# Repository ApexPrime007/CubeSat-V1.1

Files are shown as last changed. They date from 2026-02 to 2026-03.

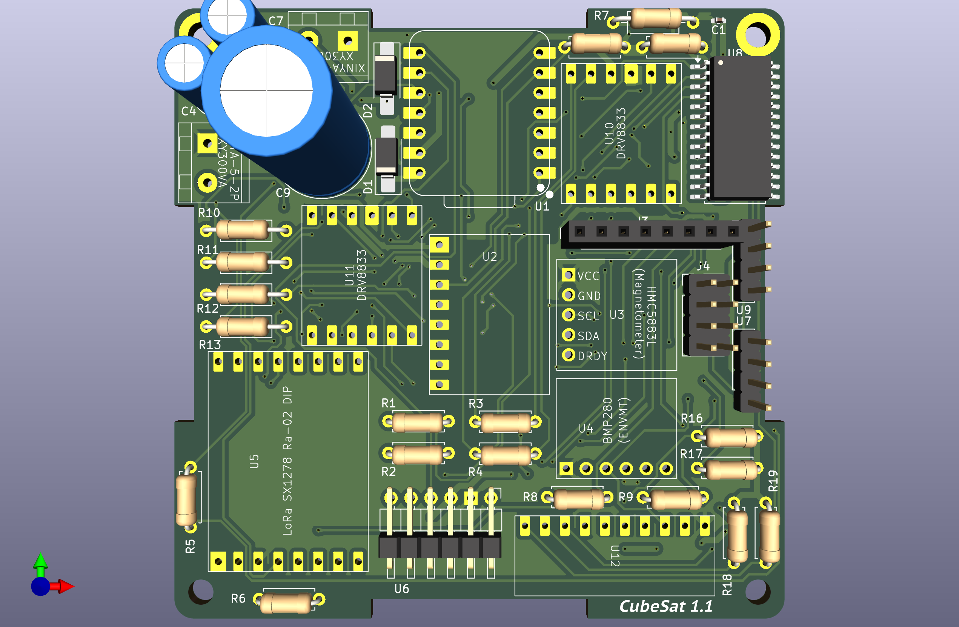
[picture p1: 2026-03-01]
CubeSat V1.1/PCB Design/CubeSat_3D_FrontView.png

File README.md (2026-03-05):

# CubeSat-V1.1
CubeSat prototype of 1U form-factor architecture, integrating inertial navigation, multi-sensor fusion, and quaternion-based EKF attitude estimation using ESP32-S3. Features GNSS time synchronization, solar-powered battery management, onboard imaging, magnetorquer-based ADCS, and long-range LoRa telemetry to a ground control station.

# Overview
The system is structured around three primary subsystems:
1. Navigation & Communication Subsystem (NCS)
2. Electrical Power Subsystem (EPS)
3. Attitude Determination & Control Subsystem (ADCS)

# Key Features
Multi-sensor integration (IMU, magnetometer, barometric sensor, GNSS), 
Quaternion-based attitude estimation with EKF, 
PPS-synchronized GNSS positioning, 
Long-range LoRa telemetry communication, 
Onboard camera image capture and transmission, 
Solar-powered battery charging and power monitoring, 
Magnetorquer-based magnetic attitude control.

# System Architecture
The ESP32-S3 acts as the central processing unit, handling:
I2C/SPI/UART-based sensor communication, 
Real-time data acquisition and calibration, 
Sensor fusion and state estimation, 
Telemetry data packaging and transmission, 
Power-aware embedded operation.

# Power System
The CubeSat prototype includes a solar-powered energy subsystem consisting of:
Solar panels for energy harvesting, 
LiPo battery for energy storage, 
Charging and protection circuitry, 
Embedded power monitoring.

# Attitude Determination & Control
Attitude estimation is performed using quaternion-based filtering techniques (including EKF).
Magnetorquers are implemented for magnetic actuation, providing a lightweight alternative to reaction wheels under CubeSat constraints.

# Applications
Educational CubeSat development, 
Inertial navigation experimentation, 
Embedded systems prototyping, 
Small satellite subsystem research.

# CubeSat Avionics System Architecture
CubeSat_ProcessFlow
This diagram represents the complete avionics data and power architecture of the CubeSat. It shows how power is distributed, how sensors communicate with the flight computer, how attitude is estimated and controlled, and how telemetry and payload data are stored and transmitted to the ground station.

The system is centered around the **ESP32-S3 Sense Flight Computer**, which manages all onboard sensors, performs data fusion, controls the attitude system, and handles telemetry transmission.

# 1. Power System Architecture
The spacecraft power system begins with the **Power System**(Solar Panels), which supplies energy to the onboard **battery**. The battery stores electrical energy generated from solar panels and supplies it to the rest of the spacecraft.The battery output is regulated using **Boost/Buck Converters** to generate stable voltage rails required by different subsystems.

Two voltage rails are generated:
### 5V Rail
The **5V rail** powers components that require higher voltage operation. These include:
* ESP32-S3 Sense Flight Computer
* 5V Current Sensor (for monitoring power consumption)
* Motor drivers used for attitude control

### 3.3V Rail
The **3.3V rail** powers all digital electronics and sensors including:
* IMU sensor
* Magnetometer
* Pressure sensor
* ADC for analog sensors
* LoRa module

Current sensors on both rails continuously monitor power usage and report the values to the flight computer.

# 2. Flight Computer
The **ESP32-S3 Sense** serves as the central processing unit of the CubeSat.
Its responsibilities include:
* Sensor data collection
* Attitude determination
* Attitude control
* Payload management
* Telemetry generation
* Communication with the ground station

The flight computer communicates with different subsystems using three main communication interfaces:
* **UART**
* **I²C Bus**
* **SPI Bus**

# 3. GNSS Navigation System
The CubeSat uses the **AI Thinker GP-02 GNSS Receiver** for positioning and time synchronization.
Communication between the GNSS module and the flight computer occurs through **UART**.

The GNSS receiver provides:
* Position data (latitude, longitude, altitude)
* Precise time synchronization
* Velocity information

This information is used for:
* Orbit determination
* Timestamping telemetry
* Navigation reference

# 4. I²C Sensor Network
Most sensors are connected to the **I²C Bus**, which allows multiple devices to communicate using only two wires.

The following sensors are connected via I²C:
### MPU6050 Accelerometer + Gyroscope
Measures:
* Linear acceleration
* Angular velocity
These measurements provide motion data required for attitude estimation.

### QMC5883L Magnetometer
Measures the **Earth’s magnetic field vector**, which is used for:
* Determining spacecraft heading
* Supporting attitude determination algorithms

### BMP280 Pressure Sensor
Measures atmospheric pressure and temperature.

Although pressure sensing has limited use in orbit, it can assist during **ground testing and launch phase monitoring**.

### MCP23017 GPIO Expander

Provides additional digital input/output pins to the flight computer.
This allows the system to connect extra sensors or control lines, in this case Motor Drivers, because exhaustion of the microcontroller GPIO pins.

### ADS1115 Analog Sensor Interface
The **ADS1115** is a high-resolution analog-to-digital converter.
It reads analog signals from **LDR Sun Sensors**.

# 5. Sun Sensor System
Multiple **LDR-based sun sensors** are mounted on different faces of the CubeSat.
Their readings are processed to determine the **direction of the Sun relative to the spacecraft**.
Processing flow:
```
LDR Sun Sensors
      ↓
ADS1115 ADC
      ↓
Sun Direction Detection
```

The calculated sun vector helps determine spacecraft orientation relative to the Sun.

# 6. 10-DOF IMU Fusion
The CubeSat performs **10 Degree-of-Freedom sensor fusion** using data from:

* MPU6050 (Accelerometer + Gyroscope)
* QMC5883L (Magnetometer)
* BMP280 (Pressure & Temperature)

This fusion algorithm estimates the spacecraft’s **attitude and orientation in space**.

Outputs include:
* Roll
* Pitch
* Yaw
* Orientation quaternion or Euler angles

# 7. Orientation Estimation
The **orientation estimation module** combines:
* IMU data
* Magnetic field data
* Sun direction vector

Using sensor fusion algorithms such as:
* Complementary filter
* Extended Kalman filter
* Madgwick filter

The output is a stable estimate of spacecraft attitude.

# 8. Attitude Control System
The spacecraft controls its orientation using **magnetorquers**.
The control loop operates as follows:
```
Orientation Estimation
        ↓
Magnetorquer Control
        ↓
DRV Motor Drivers
```
The **DRV motor drivers** control the current flowing through magnetorquer coils, generating magnetic dipoles that interact with Earth’s magnetic field to rotate the spacecraft.

# 9. Payload System (Camera)
The CubeSat includes an **OV2640 Camera Module** connected via the **SPI bus**.
The payload operation is scheduled to capture images periodically:
```
OV2640 Camera
      ↓
Capture Image Every 15 Minutes
      ↓
Store to SD Card
```
Images are then stored for later downlink.

# 10. Data Storage
All mission data is stored on the **on-board SD card**.

The SD card stores:
* Sensor data
* GNSS data
* Attitude information
* Captured images
* System logs

This ensures that no critical data is lost even if communication with the ground station is temporarily unavailable.

# 11. Telemetry Generation
Telemetry packets are prepared using the collected data.
The telemetry preparation stage includes:
* Sensor readings
* Attitude estimates
* Power system data
* GNSS position
* System health status
```
Log All Telemetry Data
        ↓
Prepare Telemetry Packet
```

# 12. Communication System
Telemetry is transmitted using the **LoRa SX1278 Radio Module**.
Communication flow:

```
Telemetry Packet
       ↓
LoRa SX1278 Radio
       ↓
Ground Control Station
```
The ground station receives the packets for:
* Mission monitoring
* Data analysis
* Command uplink

# 13. SPI Bus Conflict Control
The **SPI bus** is shared between:
* Camera module
* SD card
* LoRa radio

A **conflict control mechanism** ensures that only one device communicates on the SPI bus at a time, preventing data collisions.

# 14. Complete System Operation
The overall spacecraft operation loop follows this sequence:
1. Power system distributes regulated voltages.
2. Flight computer collects data from all sensors.
3. IMU fusion estimates spacecraft orientation.
4. Sun sensors determine sun direction.
5. Magnetorquer control adjusts spacecraft attitude.
6. Camera captures images periodically.
7. All data is logged to the SD card.
8. Telemetry packets are prepared.
9. LoRa radio transmits data to the ground station.

 This architecture ensures:

* Reliable **attitude determination**
* Efficient **power monitoring**
* Robust **data storage**
* Continuous **telemetry transmission**
* Integrated **Attitude Determination and Control System**

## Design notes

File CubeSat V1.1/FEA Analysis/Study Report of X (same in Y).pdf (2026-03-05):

# Study Report of X (same in Y)

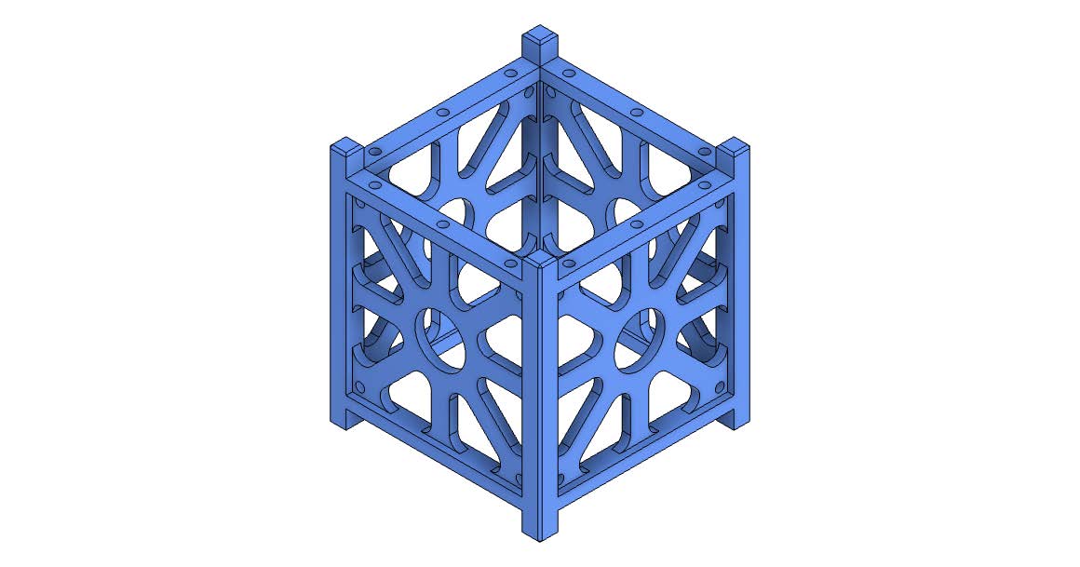
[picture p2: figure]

Analyzed File | CubeSat Structure - Main Body | Version | Autodesk Fusion (2606.1.36)
Creation Date | 2026-02-27, 20:01:35 | Author | Kumar Utkarsh

## Report Properties

Report Properties
Title | Studies
Author | Kumar Utkarsh

## Simulation Model 1

## Study 2 - Static Stress

## Study Properties

Study Properties
Study Type | Static Stress
Last Modification Date | 2026-02-27, 18:32:47

## Study Setup

Settings
General
Contact Tolerance | 0.10 mm
Remove Rigid Body Modes | No
Mesh
Average Element Size (% of model size) - Solids | 10
Scale Mesh Size Per Part | No
Average Element Size (absolute value) | -
Element Order | Parabolic
Create Curved Mesh Elements | Yes
Max. Turn Angle on Curves (Deg.) | 60
Max. Adjacent Mesh Size Ratio | 1.5
Max. Aspect Ratio | 10
Minimum Element Size (% of average size) | 20
Adaptive Mesh Refinement
Number of Refinement Steps | 0
Results Convergence Tolerance (%) | 20
Portion of Elements to Refine (%) | 10
Results for Baseline Accuracy | von Mises Stress

Materials
PLA
Components
Component | Strength
Body1 | Yield Strength
Properties
Density | 1.240E-06 kg / mm^3
Young's Modulus | 2800.00 MPa
Poisson's Ratio | 0.36
Yield Strength | 39.995 MPa
Ultimate Tensile Strength | 49.599 MPa
Thermal Conductivity | 1.600E-04 W / (mm K)
Thermal Expansion Coefficient | 7.020E-05 / K
Specific Heat | 1795.00 J / (kg K)

Contacts
Contact Type | Contact Set | Penetration Type | Bodies | Entities
Bonded
[M] Bonded1 | Symmetric | [Body1 Simulation Model 1:1||Body1 Simulation Model 1:1] | [Face 1415||Face 1441]
[M] Bonded2 | Symmetric | [Body1 Simulation Model 1:1||Body1 Simulation Model 1:1] | [Face 1461||Face 1460]

Mesh
Type | Solids
Nodes | 39529
Elements | 20437

## Load Case1

Constraints
Fixed1

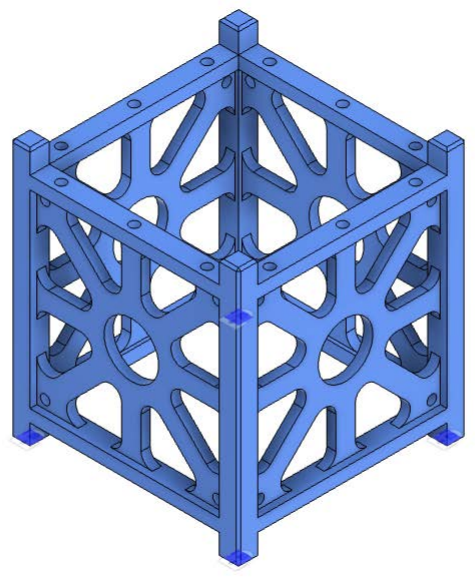
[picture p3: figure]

Type | Fixed
Ux | Fixed
Uy | Fixed
Uz | Fixed

Loads
Linear Global Load1
Type | Linear Global Load
Acceleration
X Value | 9.80 m / s^2
Y Value | 0.00 m / s^2
Z Value | 0.00 m / s^2

## Load Case1 - Guided Results

Safety Factor

With the analysis criteria in this study setup, the design is expected to bend permanently or break.

Next Steps

Below Safety Factor Target Validate your study setup
Check the loads are not set too high
Check the mesh refinement and consider increasing it in areas of high stress
Confirm your Safety Factor requirement
If the Displacement result shows high displacement, consider running a Nonlinear study to gain more insight Check other results
Examine the Below target Result visualization to see where the weakest areas are
Check the stress result to see if, and where, the material might yield
Check the displacement result to see how far from its original alignment the model has moved
Look at other results, such as reaction forces to check your study set up, or strain to check your material performance Strengthen weak areas
Add more material to weak areas
Select a material with a higher yield strength
Stiffen the design
Modify the shape with a Generative Design study Generate alternative designs Add more material to weak areas
Select a material with a higher yield strength Stiffen the design
Modify the shape with a Generative Design study Above Safety Factor Limit
Validate your study setup
Check the loads are not set too high
Check the mesh refinement and consider increasing it in areas of high stress
Confirm your Safety Factor requirement
If the Displacement result shows high displacement, consider running a Nonlinear study to gain more insight Check other results
Examine the Below target Result visualization to see where the weakest areas are
Check the stress result to see if, and where, the material might yield
Check the displacement result to see how far from its original alignment the model has moved
Look at other results, such as reaction forces to check your study set up, or strain to check your material performance Lightweight the design
Set a Safety Factor upper limit to find where material can be removed
Remove material from areas that exceed the Safety Factor upper limit
Generate alternative designs In the Generative Design workspace, create design modifications Remove unnecessary material using a Shape Optimization study

## Load Case1 - Results

Result Summary
Result type | Sub-result | Minimum | Maximum
Safety Factor
| Safety Factor | 1,119.086 | 1.66E+06
Stress
Von Mises | 2.409E-05 MPa | 0.036 MPa
1st Principal | −0.027 MPa | 0.064 MPa
3rd Principal | −0.064 MPa | 0.026 MPa
Normal XX | −0.028 MPa | 0.028 MPa
Normal YY | −0.03 MPa | 0.03 MPa
Normal ZZ | −0.062 MPa | 0.062 MPa
Shear XY | −0.003 MPa | 0.003 MPa
Shear YZ | −0.007 MPa | 0.007 MPa
Shear XZ | −0.009 MPa | 0.011 MPa
Displacement
Total | 0 mm | 8.799E-04 mm
X | 0 mm | 8.794E-04 mm
Y | −6.351E-05 mm | 6.424E-05 mm
Z | −7.924E-05 mm | 7.802E-05 mm
Reaction Force
Total | 0 N | 0.168 N
X | −0.052 N | 0.005 N
Y | −0.02 N | 0.025 N
Z | −0.159 N | 0.158 N
Strain
Equivalent | 1.291E-08 | 1.524E-05
1st Principal | 6.081E-09 | 1.73E-05
3rd Principal | −1.74E-05 | −6.129E-09
Normal XX | −5.858E-06 | 5.792E-06
Normal YY | −2.883E-06 | 2.801E-06
Normal ZZ | −1.478E-05 | 1.48E-05
Shear XY | −3.16E-06 | 3.042E-06
Shear YZ | −6.371E-06 | 6.545E-06
Shear XZ | −8.927E-06 | 1.122E-05
Contact Pressure
Total | 0 MPa | 0.058 MPa
X | −0.011 MPa | 0.01 MPa
Y | −0.01 MPa | 0.009 MPa
Z | −0.057 MPa | 0.057 MPa
Contact Force
Total | 0 N | 0.017 N
X | −0.012 N | 0.009 N
Y | −0.017 N | 0.016 N
Z | −0.009 N | 0.009 N

Safety Factor
Safety Factor

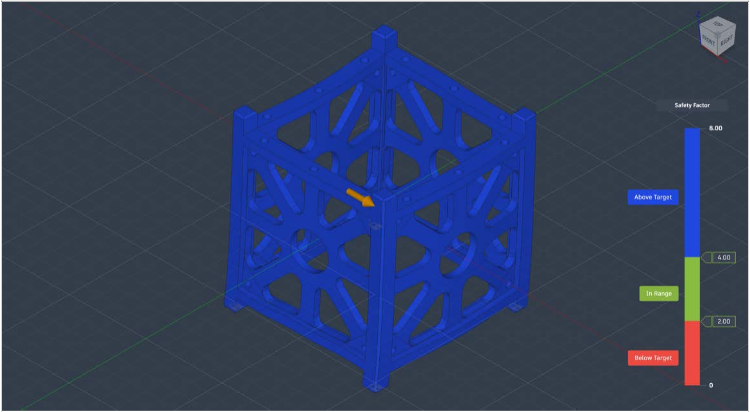
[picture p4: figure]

Stress
Von Mises

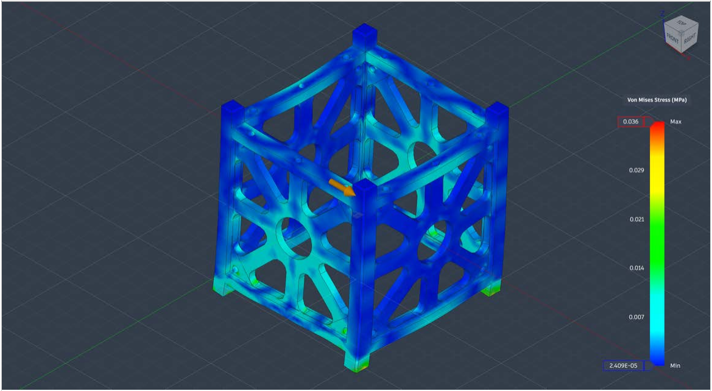
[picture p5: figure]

1st Principal

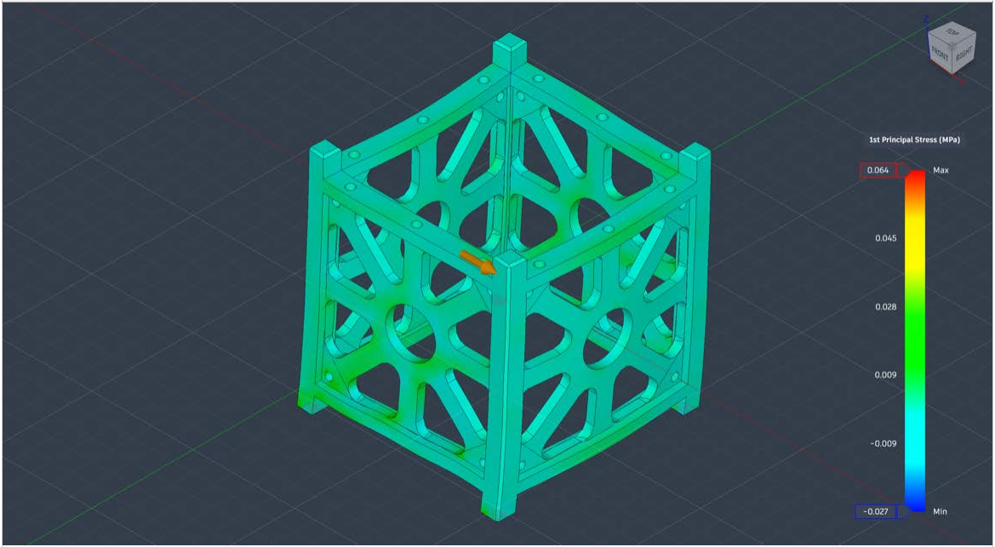
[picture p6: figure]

3rd Principal

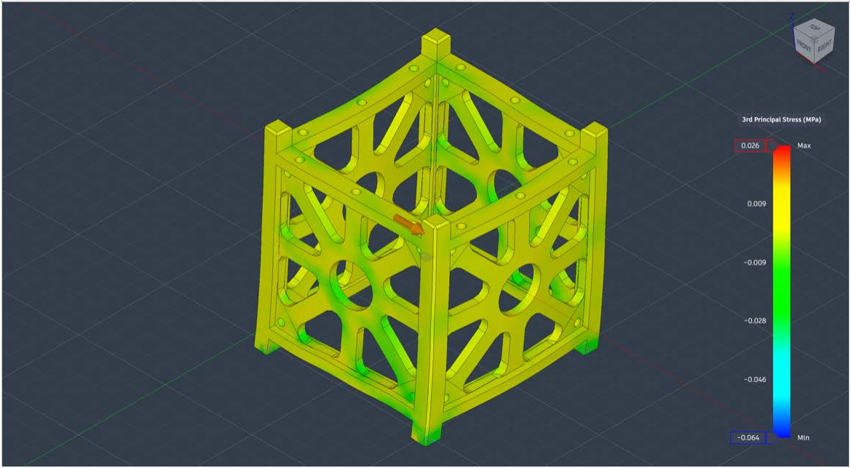
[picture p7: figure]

Displacement
Total

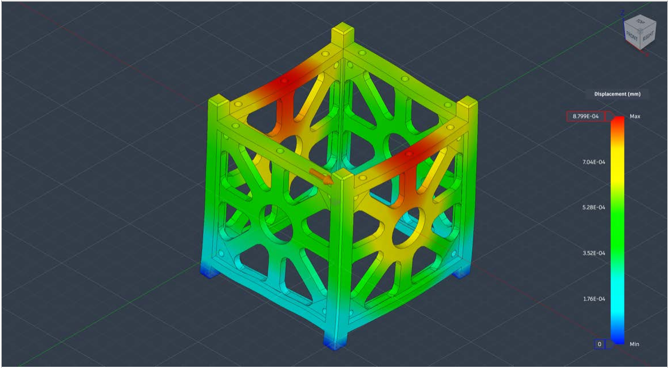
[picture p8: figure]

## Load Case2

Constraints
Fixed3

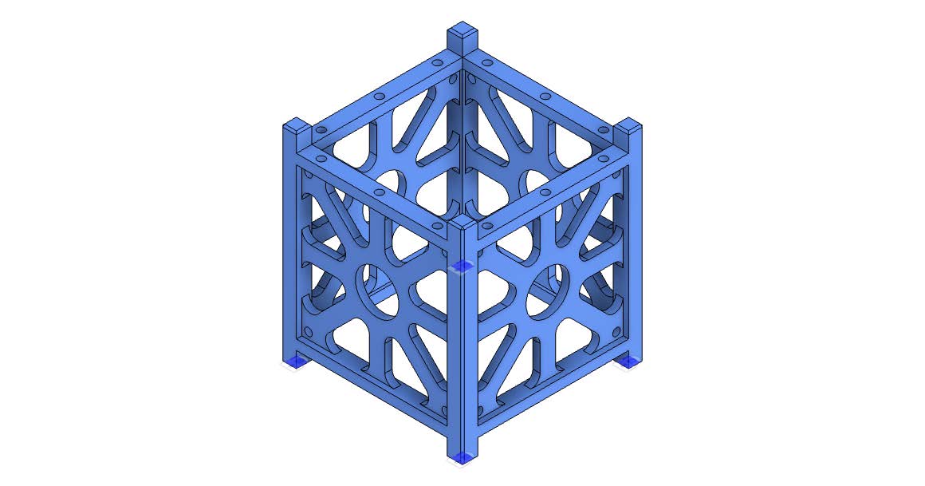
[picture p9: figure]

Type | Fixed
Ux | Fixed
Uy | Fixed
Uz | Fixed

Loads
Linear Global Load2
Type | Linear Global Load
Acceleration
X Value | 19.60 m / s^2
Y Value | 0.00 m / s^2
Z Value | 0.00 m / s^2

## Load Case2 - Guided Results

Safety Factor

With the analysis criteria in this study setup, the design is expected to bend permanently or break.

Next Steps

Below Safety Factor Target Validate your study setup
Check the loads are not set too high
Check the mesh refinement and consider increasing it in areas of high stress
Confirm your Safety Factor requirement
If the Displacement result shows high displacement, consider running a Nonlinear study to gain more insight Check other results
Examine the Below target Result visualization to see where the weakest areas are
Check the stress result to see if, and where, the material might yield
Check the displacement result to see how far from its original alignment the model has moved
Look at other results, such as reaction forces to check your study set up, or strain to check your material performance Strengthen weak areas
Add more material to weak areas
Select a material with a higher yield strength
Stiffen the design
Modify the shape with a Generative Design study Generate alternative designs Add more material to weak areas
Select a material with a higher yield strength Stiffen the design
Modify the shape with a Generative Design study Above Safety Factor Limit
Validate your study setup
Check the loads are not set too high
Check the mesh refinement and consider increasing it in areas of high stress
Confirm your Safety Factor requirement
If the Displacement result shows high displacement, consider running a Nonlinear study to gain more insight Check other results
Examine the Below target Result visualization to see where the weakest areas are
Check the stress result to see if, and where, the material might yield
Check the displacement result to see how far from its original alignment the model has moved
Look at other results, such as reaction forces to check your study set up, or strain to check your material performance Lightweight the design
Set a Safety Factor upper limit to find where material can be removed
Remove material from areas that exceed the Safety Factor upper limit
Generate alternative designs In the Generative Design workspace, create design modifications Remove unnecessary material using a Shape Optimization study

## Load Case2 - Results

Result Summary
Result type | Sub-result | Minimum | Maximum
Safety Factor
| Safety Factor | 559.543 | 830,076.00
Stress
Von Mises | 4.818E-05 MPa | 0.071 MPa
1st Principal | −0.053 MPa | 0.127 MPa
3rd Principal | −0.127 MPa | 0.053 MPa
Normal XX | −0.056 MPa | 0.055 MPa
Normal YY | −0.059 MPa | 0.059 MPa

Header
Report Properties
Simulation Model 1
Study 2 - Static Stress
Study Properties
Study Setup
Settings
Materials
Contacts
Mesh
Load Case1
Constraints
Loads
Guided Results
SafetyFactor
Results
Result Summary

Stress
Displacement
Load Case2

Guided Results
SafetyFactor
Results
Result Summary

Stress

Load Case3

Guided Results
SafetyFactor
Results
Result Summary

Stress

Load Case4

Guided Results
SafetyFactor
Results
Result Summary

Stress

Load Case5

Guided Results
SafetyFactor
Results
Result Summary

Stress
Displacement
Load Case6
Constraints
Loads
Guided Results
SafetyFactor
Results
Result Summary
Safety Factor
Stress
Displacement
Load Case7
Constraints
Loads
Guided Results
SafetyFactor
Results
Result Summary
Safety Factor
Stress
Displacement
Load Case8
Constraints
Loads
Guided Results
SafetyFactor
Results
Result Summary
Safety Factor
Stress
Displacement

Normal ZZ | −0.124 MPa | 0.124 MPa
Shear XY | −0.006 MPa | 0.006 MPa
Shear YZ | −0.013 MPa | 0.013 MPa
Shear XZ | −0.018 MPa | 0.023 MPa
Total | 0 mm | 0.002 mm
X | 0 mm | 0.002 mm
Y | −1.27E-04 mm | 1.285E-04 mm
Z | −1.585E-04 mm | 1.56E-04 mm
Reaction Force
Total | 0 N | 0.336 N
X | −0.103 N | 0.01 N
Y | −0.04 N | 0.05 N
Z | −0.317 N | 0.316 N
Strain
Equivalent | 2.583E-08 | 3.047E-05
1st Principal | 1.216E-08 | 3.461E-05
3rd Principal | −3.48E-05 | −1.226E-08
Normal XX | −1.172E-05 | 1.158E-05
Normal YY | −5.766E-06 | 5.602E-06
Normal ZZ | −2.955E-05 | 2.959E-05
Shear XY | −6.32E-06 | 6.085E-06
Shear YZ | −1.274E-05 | 1.309E-05
Shear XZ | −1.785E-05 | 2.244E-05
Contact Pressure
Total | 0 MPa | 0.117 MPa
X | −0.023 MPa | 0.021 MPa
Y | −0.019 MPa | 0.019 MPa
Z | −0.115 MPa | 0.114 MPa
Contact Force
Total | 0 N | 0.034 N
X | −0.024 N | 0.018 N
Y | −0.034 N | 0.033 N
Z | −0.018 N | 0.018 N

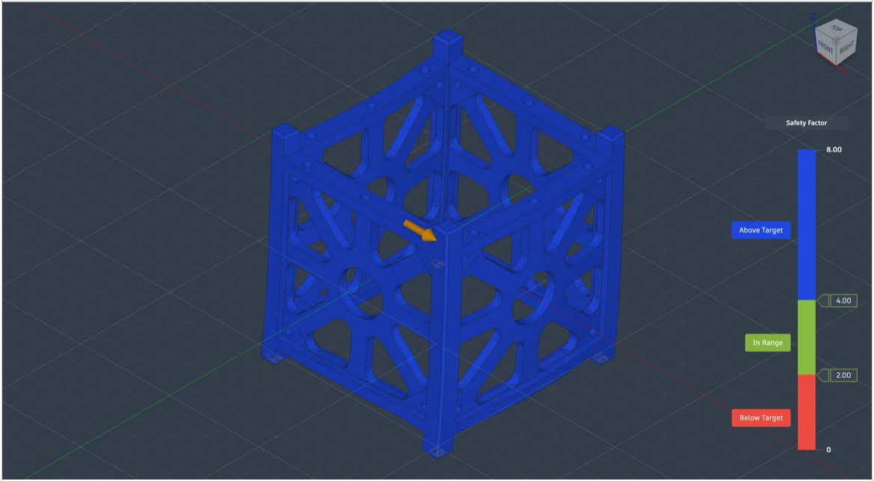
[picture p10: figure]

Stress
Von Mises

1st Principal

3rd Principal

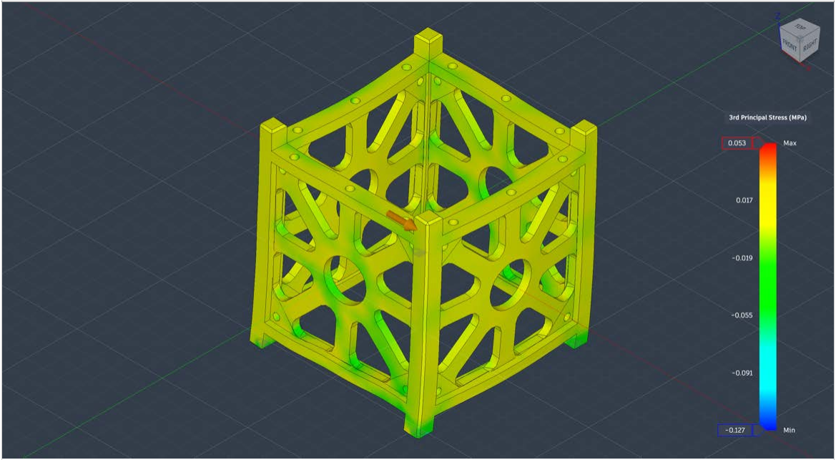
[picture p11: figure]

Displacement
Total

## Load Case3

Constraints
Fixed4
Type | Fixed
Ux | Fixed
Uy | Fixed
Uz | Fixed

Loads
Linear Global Load3
Type | Linear Global Load
Acceleration
X Value | 29.40 m / s^2
Y Value | 0.00 m / s^2
Z Value | 0.00 m / s^2

## Load Case3 - Guided Results

Safety Factor

With the analysis criteria in this study setup, the design is expected to bend permanently or break.

Next Steps

Below Safety Factor Target Validate your study setup
Check the loads are not set too high
Check the mesh refinement and consider increasing it in areas of high stress
Confirm your Safety Factor requirement
If the Displacement result shows high displacement, consider running a Nonlinear study to gain more insight Check other results
Examine the Below target Result visualization to see where the weakest areas are
Check the stress result to see if, and where, the material might yield
Check the displacement result to see how far from its original alignment the model has moved
Look at other results, such as reaction forces to check your study set up, or strain to check your material performance Strengthen weak areas
Add more material to weak areas
Select a material with a higher yield strength
Stiffen the design
Modify the shape with a Generative Design study Generate alternative designs Add more material to weak areas
Select a material with a higher yield strength Stiffen the design
Modify the shape with a Generative Design study Above Safety Factor Limit
Validate your study setup
Check the loads are not set too high
Check the mesh refinement and consider increasing it in areas of high stress
Confirm your Safety Factor requirement
If the Displacement result shows high displacement, consider running a Nonlinear study to gain more insight Check other results
Examine the Below target Result visualization to see where the weakest areas are
Check the stress result to see if, and where, the material might yield
Check the displacement result to see how far from its original alignment the model has moved
Look at other results, such as reaction forces to check your study set up, or strain to check your material performance Lightweight the design
Set a Safety Factor upper limit to find where material can be removed
Remove material from areas that exceed the Safety Factor upper limit
Generate alternative designs In the Generative Design workspace, create design modifications Remove unnecessary material using a Shape Optimization study

## Load Case3 - Results

Result Summary
Result type | Sub-result | Minimum | Maximum
Safety Factor
| Safety Factor | 373.029 | 553,384.063
Stress
Von Mises | 7.227E-05 MPa | 0.107 MPa
1st Principal | −0.08 MPa | 0.19 MPa
3rd Principal | −0.191 MPa | 0.079 MPa
Normal XX | −0.083 MPa | 0.083 MPa
Normal YY | −0.089 MPa | 0.089 MPa
Normal ZZ | −0.186 MPa | 0.186 MPa
Shear XY | −0.01 MPa | 0.009 MPa
Shear YZ | −0.02 MPa | 0.02 MPa
Shear XZ | −0.028 MPa | 0.035 MPa
Displacement
Total | 0 mm | 0.003 mm
X | 0 mm | 0.003 mm
Y | −1.905E-04 mm | 1.927E-04 mm
Z | −2.377E-04 mm | 2.341E-04 mm
Reaction Force
Total | 0 N | 0.503 N
X | −0.155 N | 0.015 N
Y | −0.059 N | 0.075 N
Z | −0.476 N | 0.474 N
Strain
Equivalent | 3.874E-08 | 4.571E-05
1st Principal | 1.824E-08 | 5.191E-05
3rd Principal | −5.221E-05 | −1.839E-08
Normal XX | −1.758E-05 | 1.738E-05
Normal YY | −8.649E-06 | 8.402E-06
Normal ZZ | −4.433E-05 | 4.439E-05
Shear XY | −9.481E-06 | 9.127E-06
Shear YZ | −1.911E-05 | 1.964E-05
Shear XZ | −2.678E-05 | 3.366E-05
Contact Pressure
Total | 0 MPa | 0.175 MPa
X | −0.034 MPa | 0.031 MPa
Y | −0.029 MPa | 0.029 MPa
Z | −0.172 MPa | 0.172 MPa
Contact Force
Total | 0 N | 0.051 N
X | −0.036 N | 0.027 N
Y | −0.051 N | 0.049 N
Z | −0.026 N | 0.026 N

Safety Factor
Safety Factor

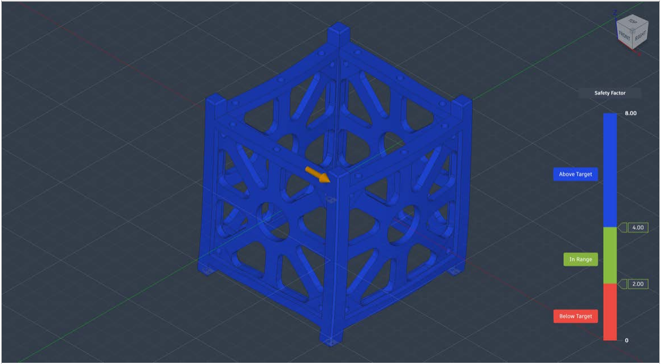
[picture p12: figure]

Stress
Von Mises

1st Principal

3rd Principal

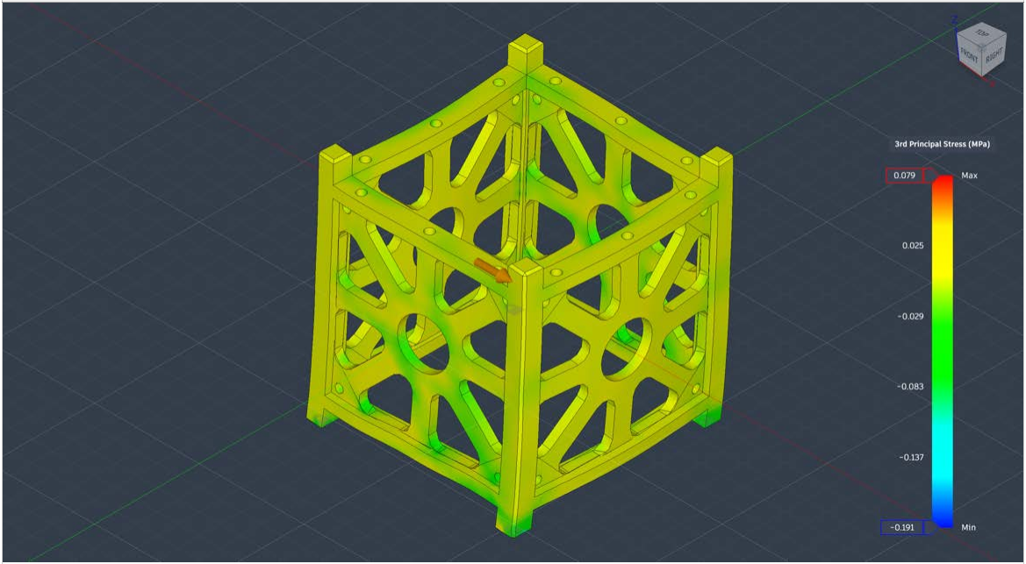
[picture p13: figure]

Displacement
Total

## Load Case4

Constraints
Fixed5
Type | Fixed
Ux | Fixed
Uy | Fixed
Uz | Fixed

Linear Global Load4

Type | Linear Global Load
Acceleration
X Value | 49.00 m / s^2
Y Value | 0.00 m / s^2
Z Value | 0.00 m / s^2

## Load Case4 - Guided Results

With the analysis criteria in this study setup, there is opportunity to reduce the volume of material and cost of this design.

Next Steps

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

## Load Case4 - Results

Result Summary
Result type | Sub-result | Minimum | Maximum
Safety Factor
| Safety Factor | 223.817 | 332,030.406
Stress
Von Mises | 1.205E-04 MPa | 0.179 MPa
1st Principal | −0.133 MPa | 0.317 MPa
3rd Principal | −0.318 MPa | 0.132 MPa
Normal XX | −0.139 MPa | 0.138 MPa
Normal YY | −0.148 MPa | 0.148 MPa
Normal ZZ | −0.31 MPa | 0.31 MPa
Shear XY | −0.016 MPa | 0.016 MPa
Shear YZ | −0.033 MPa | 0.034 MPa
Shear XZ | −0.046 MPa | 0.058 MPa
Displacement
Total | 0 mm | 0.004 mm
X | 0 mm | 0.004 mm
Y | −3.176E-04 mm | 3.212E-04 mm
Z | −3.962E-04 mm | 3.901E-04 mm
Reaction Force
Total | 0 N | 0.839 N
X | −0.258 N | 0.024 N
Y | −0.099 N | 0.124 N
Z | −0.793 N | 0.79 N
Strain
Equivalent | 6.457E-08 | 7.618E-05
1st Principal | 3.04E-08 | 8.652E-05
3rd Principal | −8.701E-05 | −3.065E-08
Normal XX | −2.929E-05 | 2.896E-05
Normal YY | −1.442E-05 | 1.40E-05
Normal ZZ | −7.389E-05 | 7.398E-05
Shear XY | −1.58E-05 | 1.521E-05
Shear YZ | −3.186E-05 | 3.273E-05
Shear XZ | −4.463E-05 | 5.61E-05
Contact Pressure
Total | 0 MPa | 0.292 MPa
X | −0.057 MPa | 0.052 MPa
Y | −0.048 MPa | 0.048 MPa
Z | −0.287 MPa | 0.286 MPa
Contact Force
Total | 0 N | 0.086 N
X | −0.059 N | 0.045 N
Y | −0.085 N | 0.082 N
Z | −0.044 N | 0.044 N

Safety Factor
Safety Factor

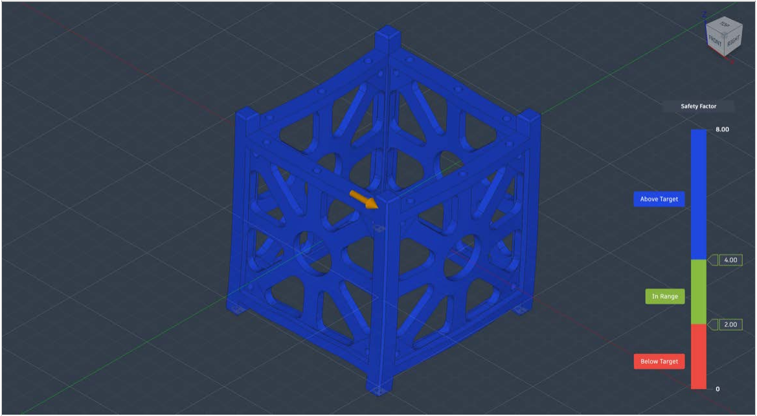
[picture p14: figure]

Stress
Von Mises

1st Principal

3rd Principal

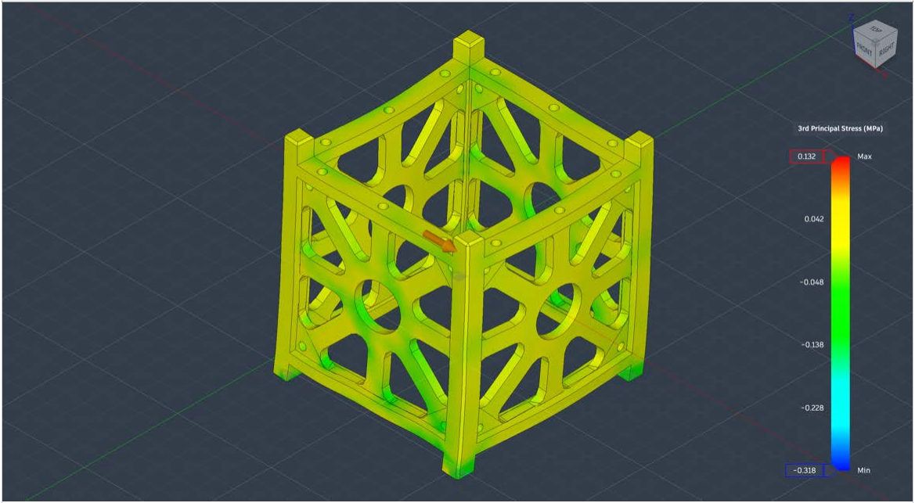
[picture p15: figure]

Displacement
Total

## Load Case5

Constraints
Fixed6
Type | Fixed
Ux | Fixed
Uy | Fixed
Uz | Fixed

Loads
Linear Global Load5
Type | Linear Global Load
Acceleration
X Value | 58.80 m / s^2
Y Value | 0.00 m / s^2
Z Value | 0.00 m / s^2

## Load Case5 - Guided Results

Safety Factor

With the analysis criteria in this study setup, there is opportunity to reduce the volume of material and cost of this design.

Next Steps

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

## Load Case5 - Results

Result Summary
Result type | Sub-result | Minimum | Maximum
Safety Factor
| Safety Factor | 186.514 | 276,692.031
Stress
Von Mises | 1.445E-04 MPa | 0.214 MPa
1st Principal | −0.159 MPa | 0.381 MPa
3rd Principal | −0.381 MPa | 0.159 MPa
Normal XX | −0.166 MPa | 0.166 MPa
Normal YY | −0.178 MPa | 0.177 MPa
Normal ZZ | −0.372 MPa | 0.372 MPa
Shear XY | −0.019 MPa | 0.019 MPa
Shear YZ | −0.039 MPa | 0.04 MPa
Shear XZ | −0.055 MPa | 0.069 MPa
Displacement
Total | 0 mm | 0.005 mm
X | 0 mm | 0.005 mm
Y | −3.811E-04 mm | 3.855E-04 mm
Z | −4.755E-04 mm | 4.681E-04 mm
Reaction Force
Total | 0 N | 1.007 N
X | −0.31 N | 0.029 N
Y | −0.119 N | 0.149 N
Z | −0.952 N | 0.949 N
Strain
Equivalent | 7.749E-08 | 9.141E-05
1st Principal | 3.648E-08 | 1.038E-04
3rd Principal | −1.044E-04 | −3.678E-08
Normal XX | −3.515E-05 | 3.475E-05
Normal YY | −1.73E-05 | 1.68E-05
Normal ZZ | −8.866E-05 | 8.878E-05
Shear XY | −1.896E-05 | 1.825E-05
Shear YZ | −3.823E-05 | 3.927E-05
Shear XZ | −5.356E-05 | 6.732E-05
Contact Pressure
Total | 0 MPa | 0.35 MPa
X | −0.068 MPa | 0.062 MPa
Y | −0.057 MPa | 0.057 MPa
Z | −0.344 MPa | 0.343 MPa
Contact Force
Total | 0 N | 0.103 N
X | −0.071 N | 0.054 N
Y | −0.102 N | 0.098 N
Z | −0.053 N | 0.053 N

Safety Factor
Safety Factor

Stress
Von Mises

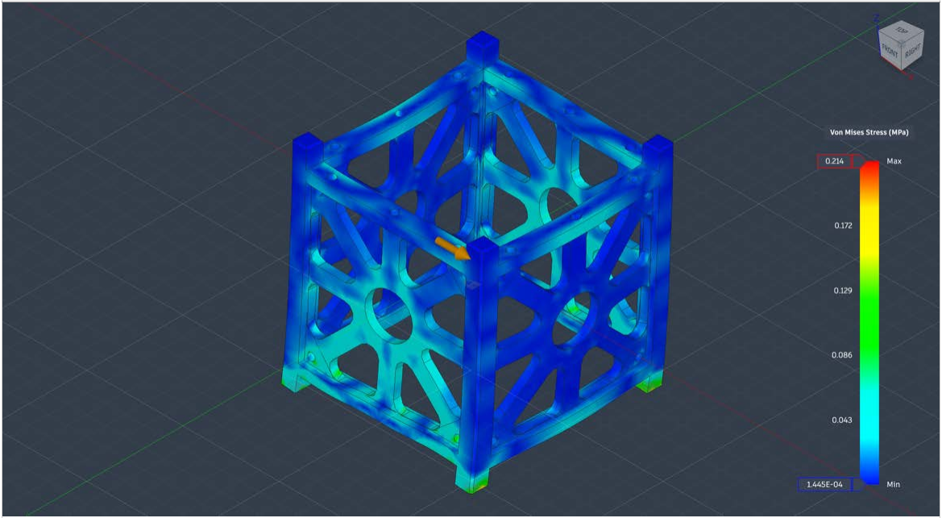
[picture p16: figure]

1st Principal

3rd Principal

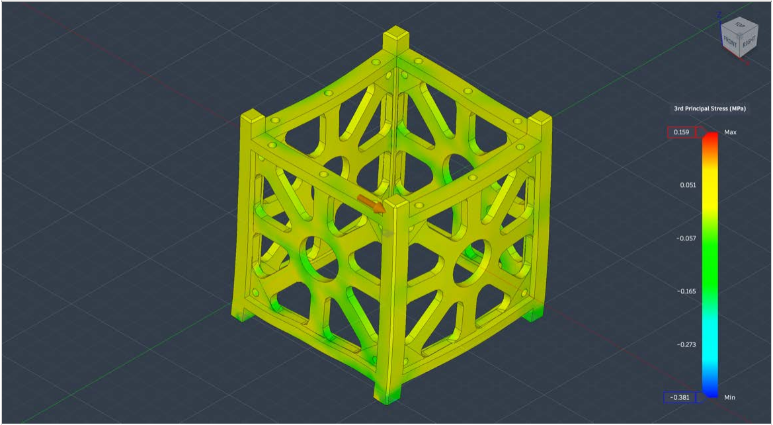
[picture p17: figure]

Total

## Load Case6

Fixed8

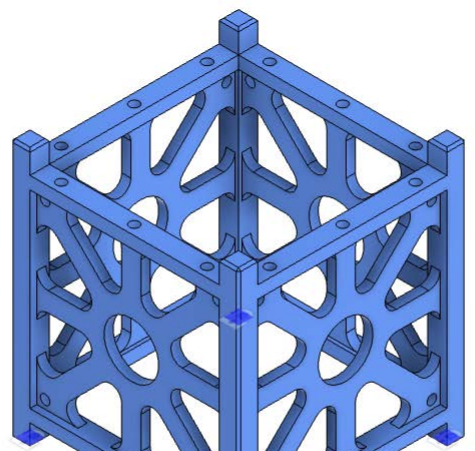
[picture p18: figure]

Type | Fixed
Ux | Fixed
Uy | Fixed
Uz | Fixed

Linear Global Load7

Type | Linear Global Load
Acceleration
X Value | 78.40 m / s^2
Y Value | 0.00 m / s^2
Z Value | 0.00 m / s^2

## Load Case6 - Guided Results

With the analysis criteria in this study setup, there is opportunity to reduce the volume of material and cost of this design.

Next Steps

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

## Load Case6 - Results

Result Summary
Result type | Sub-result | Minimum | Maximum
Safety Factor
| Safety Factor | 139.886 | 207,519.00
Stress
Von Mises | 1.927E-04 MPa | 0.286 MPa
1st Principal | −0.212 MPa | 0.508 MPa
3rd Principal | −0.508 MPa | 0.212 MPa
Normal XX | −0.222 MPa | 0.221 MPa
Normal YY | −0.238 MPa | 0.237 MPa
Normal ZZ | −0.496 MPa | 0.496 MPa
Shear XY | −0.026 MPa | 0.025 MPa
Shear YZ | −0.052 MPa | 0.054 MPa
Shear XZ | −0.073 MPa | 0.092 MPa
Displacement
Total | 0 mm | 0.007 mm
X | 0 mm | 0.007 mm
Y | −5.081E-04 mm | 5.14E-04 mm
Z | −6.339E-04 mm | 6.241E-04 mm
Reaction Force
Total | 0 N | 1.343 N
X | −0.413 N | 0.039 N
Y | −0.159 N | 0.199 N
Z | −1.27 N | 1.265 N
Strain
Equivalent | 1.033E-07 | 1.219E-04
1st Principal | 4.864E-08 | 1.384E-04
3rd Principal | −1.392E-04 | −4.903E-08
Normal XX | −4.687E-05 | 4.634E-05
Normal YY | −2.306E-05 | 2.241E-05
Normal ZZ | −1.182E-04 | 1.184E-04
Shear XY | −2.528E-05 | 2.434E-05
Shear YZ | −5.097E-05 | 5.236E-05
Shear XZ | −7.142E-05 | 8.976E-05
Contact Pressure
Total | 0 MPa | 0.467 MPa
X | −0.091 MPa | 0.083 MPa
Y | −0.076 MPa | 0.076 MPa
Z | −0.459 MPa | 0.457 MPa
Contact Force
Total | 0 N | 0.137 N
X | −0.095 N | 0.072 N
Y | −0.136 N | 0.131 N
Z | −0.071 N | 0.071 N

Safety Factor
Safety Factor

Stress
Von Mises

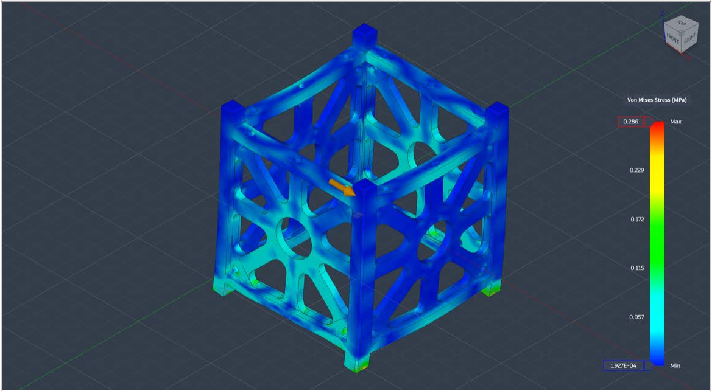
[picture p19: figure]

1st Principal

3rd Principal

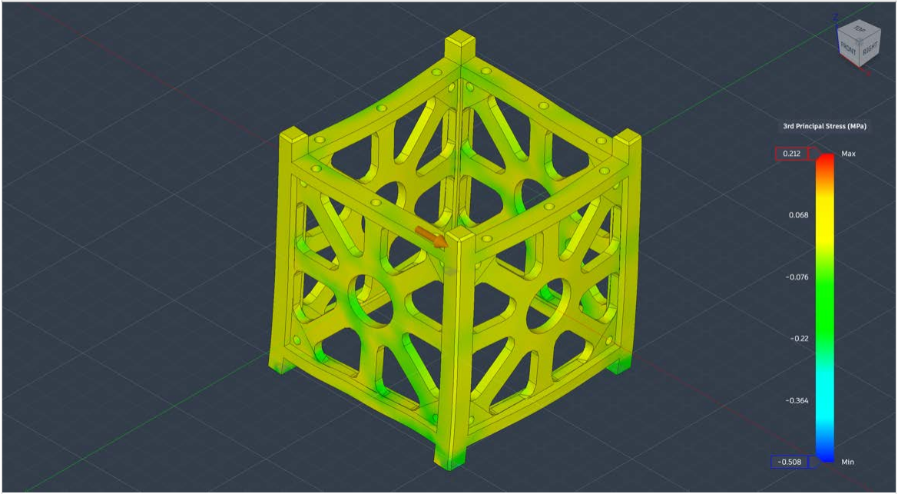
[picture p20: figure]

Displacement
Total

## Load Case7

Constraints
Fixed9
Type | Fixed
Ux | Fixed
Uy | Fixed
Uz | Fixed

Loads
Linear Global Load8
Type | Linear Global Load
Acceleration
X Value | 98.00 m / s^2
Y Value | 0.00 m / s^2
Z Value | 0.00 m / s^2

## Load Case7 - Guided Results

Safety Factor

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

Next Steps

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

## Load Case7 - Results

Result Summary
Result type | Sub-result | Minimum | Maximum
Safety Factor
| Safety Factor | 111.909 | 166,015.203
Stress
Von Mises | 2.409E-04 MPa | 0.357 MPa
1st Principal | −0.266 MPa | 0.635 MPa
3rd Principal | −0.636 MPa | 0.265 MPa
Normal XX | −0.277 MPa | 0.276 MPa
Normal YY | −0.297 MPa | 0.296 MPa
Normal ZZ | −0.62 MPa | 0.62 MPa
Shear XY | −0.033 MPa | 0.031 MPa
Shear YZ | −0.066 MPa | 0.067 MPa
Shear XZ | −0.092 MPa | 0.116 MPa
Displacement
Total | 0 mm | 0.009 mm
X | 0 mm | 0.009 mm
Y | −6.351E-04 mm | 6.424E-04 mm
Z | −7.924E-04 mm | 7.802E-04 mm
Reaction Force
Total | 0 N | 1.678 N
X | −0.516 N | 0.049 N
Y | −0.198 N | 0.249 N
Z | −1.587 N | 1.581 N
Strain
Equivalent | 1.291E-07 | 1.524E-04
1st Principal | 6.081E-08 | 1.73E-04
3rd Principal | −1.74E-04 | −6.129E-08
Normal XX | −5.858E-05 | 5.792E-05
Normal YY | −2.883E-05 | 2.801E-05
Normal ZZ | −1.478E-04 | 1.48E-04
Shear XY | −3.16E-05 | 3.042E-05
Shear YZ | −6.371E-05 | 6.545E-05
Shear XZ | −8.927E-05 | 1.122E-04
Contact Pressure
Total | 0 MPa | 0.584 MPa
X | −0.114 MPa | 0.103 MPa
Y | −0.096 MPa | 0.095 MPa
Z | −0.573 MPa | 0.572 MPa
Contact Force
Total | 0 N | 0.171 N
X | −0.119 N | 0.091 N
Y | −0.169 N | 0.164 N
Z | −0.088 N | 0.088 N

Safety Factor
Safety Factor

Stress
Von Mises

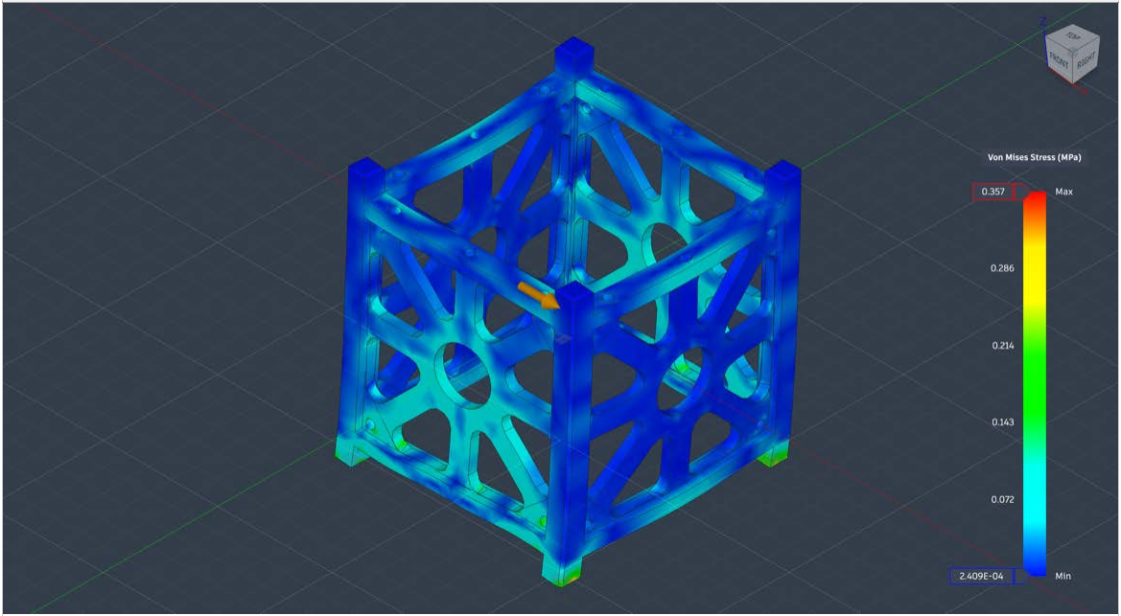
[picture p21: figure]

1st Principal

3rd Principal

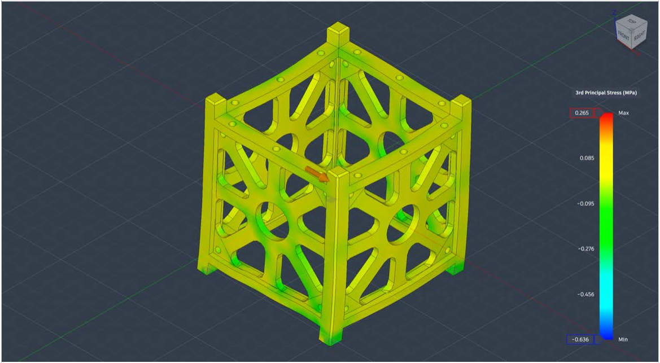
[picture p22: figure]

## Load Case8

Fixed10

Type | Fixed
Ux | Fixed
Uy | Fixed
Uz | Fixed

Loads
Linear Global Load9

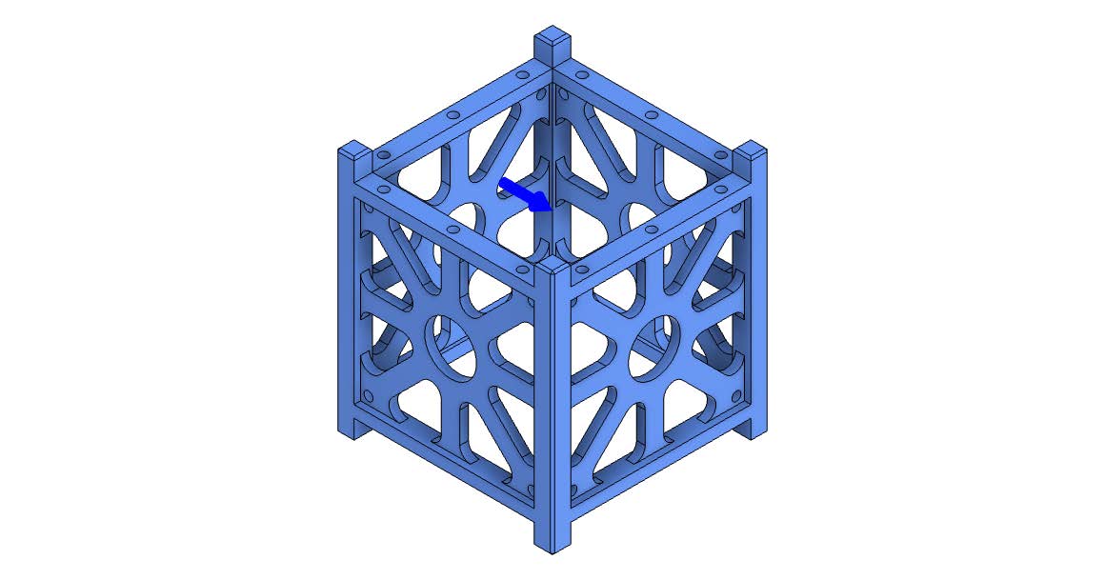
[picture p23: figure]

Type | Linear Global Load
Acceleration
X Value | 147.00 m / s^2
Y Value | 0.00 m / s^2
Z Value | 0.00 m / s^2

## Load Case8 - Guided Results

Safety Factor

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

Next Steps

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

## Load Case8 - Results

Result Summary
Result type | Sub-result | Minimum | Maximum
Safety Factor
| Safety Factor | 74.606 | 110,676.805
Stress
Von Mises | 3.614E-04 MPa | 0.536 MPa
1st Principal | −0.398 MPa | 0.952 MPa
3rd Principal | −0.954 MPa | 0.397 MPa
Normal XX | −0.416 MPa | 0.414 MPa
Normal YY | −0.445 MPa | 0.444 MPa
Normal ZZ | −0.93 MPa | 0.93 MPa
Shear XY | −0.049 MPa | 0.047 MPa
Shear YZ | −0.098 MPa | 0.101 MPa
Shear XZ | −0.138 MPa | 0.173 MPa
Displacement
Total | 0 mm | 0.013 mm
X | 0 mm | 0.013 mm
Y | −9.527E-04 mm | 9.637E-04 mm
Z | −0.001 mm | 0.001 mm
Reaction Force
Total | 0 N | 2.517 N
X | −0.774 N | 0.073 N
Y | −0.298 N | 0.373 N
Z | −2.381 N | 2.371 N
Strain
Equivalent | 1.937E-07 | 2.285E-04
1st Principal | 9.121E-08 | 2.595E-04
3rd Principal | −2.61E-04 | −9.194E-08
Normal XX | −8.788E-05 | 8.689E-05
Normal YY | −4.325E-05 | 4.201E-05
Normal ZZ | −2.217E-04 | 2.22E-04
Shear XY | −4.74E-05 | 4.564E-05
Shear YZ | −9.557E-05 | 9.818E-05
Shear XZ | −1.339E-04 | 1.683E-04
Contact Pressure
Total | 0 MPa | 0.876 MPa
X | −0.171 MPa | 0.155 MPa
Y | −0.143 MPa | 0.143 MPa
Z | −0.86 MPa | 0.857 MPa
Contact Force
Total | 0 N | 0.257 N
X | −0.178 N | 0.136 N
Y | −0.254 N | 0.246 N
Z | −0.133 N | 0.132 N

Safety Factor
Safety Factor

Stress
Von Mises

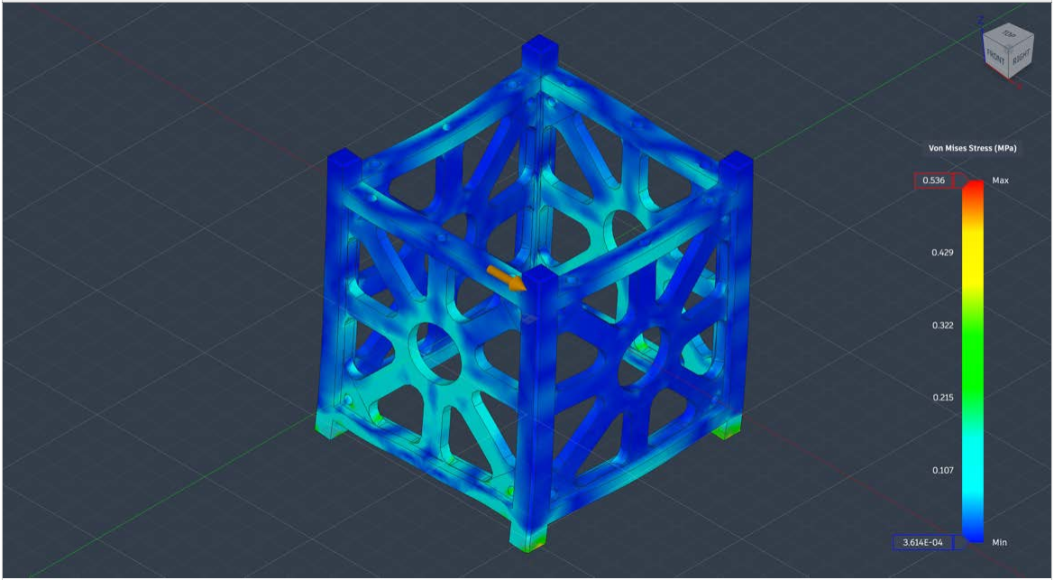
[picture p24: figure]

1st Principal

3rd Principal

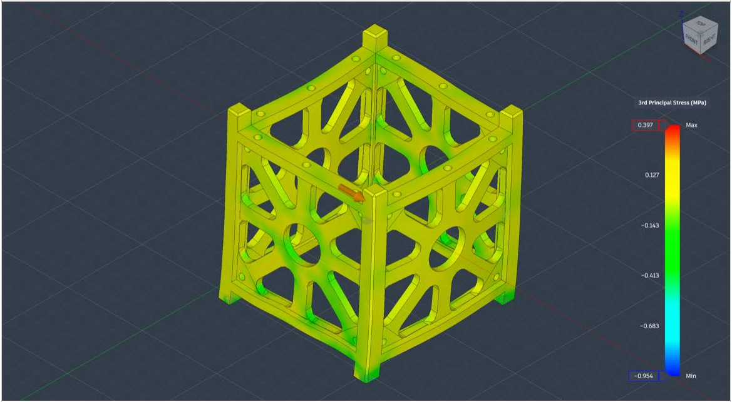
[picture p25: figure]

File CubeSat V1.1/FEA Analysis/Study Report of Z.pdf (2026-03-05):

# Study Report


Analyzed File | CubeSat Structure - Main Body | Version | Autodesk Fusion (2606.1.36)
Creation Date | 2026-02-27, 20:10:52 | Author | Kumar Utkarsh

## Report Properties

Report Properties
Title | Studies
Author | Kumar Utkarsh

## Simulation Model 1

## Study 1 - Static Stress

## Study Properties

Study Properties
Study Type | Static Stress
Last Modification Date | 2026-02-27, 18:23:47

## Study Setup

Settings
General
Contact Tolerance | 0.10 mm
Remove Rigid Body Modes | No
Mesh
Average Element Size (% of model size) - Solids | 10
Scale Mesh Size Per Part | No
Average Element Size (absolute value) | -
Element Order | Parabolic
Create Curved Mesh Elements | Yes
Max. Turn Angle on Curves (Deg.) | 60
Max. Adjacent Mesh Size Ratio | 1.5
Max. Aspect Ratio | 10
Minimum Element Size (% of average size) | 20
Adaptive Mesh Refinement
Number of Refinement Steps | 0
Results Convergence Tolerance (%) | 20
Portion of Elements to Refine (%) | 10
Results for Baseline Accuracy | von Mises Stress

Materials
PLA
Components
Component | Strength
Body1 | Yield Strength
Properties
Density | 1.240E-06 kg / mm^3
Young's Modulus | 2800.00 MPa
Poisson's Ratio | 0.36
Yield Strength | 39.995 MPa
Ultimate Tensile Strength | 49.599 MPa
Thermal Conductivity | 1.600E-04 W / (mm K)
Thermal Expansion Coefficient | 7.020E-05 / K
Specific Heat | 1795.00 J / (kg K)

Contacts
Contact Type | Contact Set | Penetration Type | Bodies | Entities
Bonded
[M] Bonded1 | Symmetric | [Body1 Simulation Model 1:1||Body1 Simulation Model 1:1] | [Face 1415||Face 1441]
[M] Bonded2 | Symmetric | [Body1 Simulation Model 1:1||Body1 Simulation Model 1:1] | [Face 1461||Face 1460]

Mesh
Type | Solids
Nodes | 39529
Elements | 20437

## Load Case1

Constraints
Fixed1


Type | Fixed
Ux | Fixed
Uy | Fixed
Uz | Fixed

Loads
Linear Global Load1
Type | Linear Global Load
Acceleration
X Value | 0.00 m / s^2
Y Value | 0.00 m / s^2
Z Value | 9.80 m / s^2

## Load Case1 - Guided Results

Safety Factor

With the analysis criteria in this study setup, the design is expected to bend permanently or break.

Next Steps

Below Safety Factor Target Validate your study setup
Check the loads are not set too high
Check the mesh refinement and consider increasing it in areas of high stress
Confirm your Safety Factor requirement
If the Displacement result shows high displacement, consider running a Nonlinear study to gain more insight Check other results
Examine the Below target Result visualization to see where the weakest areas are
Check the stress result to see if, and where, the material might yield
Check the displacement result to see how far from its original alignment the model has moved
Look at other results, such as reaction forces to check your study set up, or strain to check your material performance Strengthen weak areas
Add more material to weak areas
Select a material with a higher yield strength
Stiffen the design
Modify the shape with a Generative Design study Generate alternative designs Add more material to weak areas
Select a material with a higher yield strength Stiffen the design
Modify the shape with a Generative Design study Above Safety Factor Limit
Validate your study setup
Check the loads are not set too high
Check the mesh refinement and consider increasing it in areas of high stress
Confirm your Safety Factor requirement
If the Displacement result shows high displacement, consider running a Nonlinear study to gain more insight Check other results
Examine the Below target Result visualization to see where the weakest areas are
Check the stress result to see if, and where, the material might yield
Check the displacement result to see how far from its original alignment the model has moved
Look at other results, such as reaction forces to check your study set up, or strain to check your material performance Lightweight the design
Set a Safety Factor upper limit to find where material can be removed
Remove material from areas that exceed the Safety Factor upper limit
Generate alternative designs In the Generative Design workspace, create design modifications Remove unnecessary material using a Shape Optimization study

## Load Case1 - Results

Result Summary
Result type | Sub-result | Minimum | Maximum
Safety Factor
| Safety Factor | 4,730.243 | 2.93E+06
Stress
Von Mises | 1.365E-05 MPa | 0.009 MPa
1st Principal | −4.034E-04 MPa | 0.014 MPa
3rd Principal | −0.003 MPa | 0.005 MPa
Normal XX | −0.003 MPa | 0.006 MPa
Normal YY | −0.002 MPa | 0.006 MPa
Normal ZZ | −0.002 MPa | 0.014 MPa
Shear XY | −8.129E-04 MPa | 7.955E-04 MPa
Shear YZ | −0.003 MPa | 0.003 MPa
Shear XZ | −0.003 MPa | 0.004 MPa
Displacement
Total | 0 mm | 8.142E-05 mm
X | −8.141E-06 mm | 8.518E-06 mm
Y | −8.781E-06 mm | 8.154E-06 mm
Z | 0 mm | 8.141E-05 mm
Reaction Force
Total | 0 N | 0.037 N
X | −0.01 N | 0.01 N
Y | −0.009 N | 0.008 N
Z | −0.035 N | 0 N
Strain
Equivalent | 5.108E-09 | 4.545E-06
1st Principal | 4.585E-09 | 5.004E-06
3rd Principal | −2.375E-06 | −2.868E-09
Normal XX | −1.011E-06 | 9.534E-07
Normal YY | −1.153E-06 | 9.577E-07
Normal ZZ | −3.533E-07 | 3.275E-06
Shear XY | −7.896E-07 | 7.728E-07
Shear YZ | −2.799E-06 | 2.402E-06
Shear XZ | −2.489E-06 | 3.554E-06
Contact Pressure
Total | 0 MPa | 0.013 MPa
X | −0.003 MPa | 0.002 MPa
Y | −0.002 MPa | 0.003 MPa
Z | −0.013 MPa | 0.002 MPa
Contact Force
Total | 0 N | 0.004 N
X | −0.003 N | 0.003 N
Y | −0.004 N | 0.004 N
Z | −0.002 N | 0.002 N

Safety Factor
Safety Factor

Stress
Von Mises


1st Principal

3rd Principal

Displacement
Total


## Load Case2

Constraints
Fixed3
Type | Fixed
Ux | Fixed
Uy | Fixed
Uz | Fixed

Loads
Linear Global Load2
Type | Linear Global Load
Acceleration
X Value | 0.00 m / s^2
Y Value | 0.00 m / s^2
Z Value | 19.60 m / s^2

## Load Case2 - Guided Results

Safety Factor

With the analysis criteria in this study setup, there is opportunity to reduce the volume of material and cost of this design.

Next Steps

Above Safety Factor Limit
Validate your study setup
Check the loads are not set too high
Check the mesh refinement and consider increasing it in areas of high stress
Confirm your Safety Factor requirement
If the Displacement result shows high displacement, consider running a Nonlinear study to gain more insight Check other results
Examine the Below target Result visualization to see where the weakest areas are
Check the stress result to see if, and where, the material might yield
Check the displacement result to see how far from its original alignment the model has moved
Look at other results, such as reaction forces to check your study set up, or strain to check your material performance Lightweight the design
Set a Safety Factor upper limit to find where material can be removed
Remove material from areas that exceed the Safety Factor upper limit
Generate alternative designs In the Generative Design workspace, create design modifications Remove unnecessary material using a Shape Optimization study

## Load Case2 - Results

Result Summary
Result type | Sub-result | Minimum | Maximum
Safety Factor
| Safety Factor | 2,365.121 | 1.465E+06
Stress
Von Mises | 2.73E-05 MPa | 0.017 MPa
1st Principal | −8.068E-04 MPa | 0.029 MPa
3rd Principal | −0.006 MPa | 0.011 MPa
Normal XX | −0.005 MPa | 0.013 MPa
Normal YY | −0.005 MPa | 0.013 MPa
Normal ZZ | −0.003 MPa | 0.027 MPa
Shear XY | −0.002 MPa | 0.002 MPa
Shear YZ | −0.006 MPa | 0.005 MPa
Shear XZ | −0.005 MPa | 0.007 MPa
Displacement
Total | 0 mm | 1.628E-04 mm
X | −1.628E-05 mm | 1.704E-05 mm
Y | −1.756E-05 mm | 1.631E-05 mm
Z | 0 mm | 1.628E-04 mm
Reaction Force
Total | 0 N | 0.074 N
X | −0.021 N | 0.021 N
Y | −0.017 N | 0.016 N
Z | −0.07 N | 0 N
Strain
Equivalent | 1.022E-08 | 9.091E-06

Header
Report Properties
Simulation Model 1
Study 1 - Static Stress
Study Properties
Study Setup
Settings
Materials
Contacts
Mesh
Load Case1
Constraints
Loads
Guided Results
SafetyFactor
Results
Result Summary

Stress

Load Case2
Constraints
Loads
Guided Results
SafetyFactor
Results
Result Summary

Stress

Load Case3
Constraints
Loads
Guided Results
SafetyFactor
Results
Result Summary

Stress

Load Case4
Constraints
Loads
Guided Results
SafetyFactor
Results
Result Summary

Stress

Load Case5
Constraints
Loads
Guided Results
SafetyFactor
Results
Result Summary

Stress
Displacement
Load Case6
Constraints
Loads
Guided Results
SafetyFactor
Results
Result Summary
Safety Factor
Stress
Displacement
Load Case7
Constraints
Loads
Guided Results
SafetyFactor
Results
Result Summary
Safety Factor
Stress
Displacement
Load Case8
Constraints
Loads
Guided Results
SafetyFactor
Results
Result Summary
Safety Factor
Stress
Displacement

Equivalent | 1.022E-08 | 9.091E-06
1st Principal | 9.169E-09 | 1.001E-05
3rd Principal | −4.749E-06 | −5.736E-09
Normal XX | −2.021E-06 | 1.907E-06
Normal YY | −2.305E-06 | 1.915E-06
Normal ZZ | −7.065E-07 | 6.549E-06
Shear XY | −1.579E-06 | 1.546E-06
Shear YZ | −5.599E-06 | 4.803E-06
Shear XZ | −4.977E-06 | 7.108E-06
Contact Pressure
Total | 0 MPa | 0.026 MPa
X | −0.005 MPa | 0.005 MPa
Y | −0.004 MPa | 0.005 MPa
Z | −0.026 MPa | 0.003 MPa
Contact Force
Total | 0 N | 0.008 N
X | −0.006 N | 0.006 N
Y | −0.008 N | 0.008 N
Z | −0.005 N | 0.003 N


Stress
Von Mises

1st Principal

3rd Principal

Displacement
Total


## Load Case3

Constraints
Fixed4
Type | Fixed
Ux | Fixed
Uy | Fixed
Uz | Fixed

Loads
Linear Global Load3
Type | Linear Global Load
Acceleration
X Value | 0.00 m / s^2
Y Value | 0.00 m / s^2
Z Value | 29.40 m / s^2

## Load Case3 - Guided Results

Safety Factor

With the analysis criteria in this study setup, there is opportunity to reduce the volume of material and cost of this design.

Next Steps

Above Safety Factor Limit
Validate your study setup
Check the loads are not set too high
Check the mesh refinement and consider increasing it in areas of high stress
Confirm your Safety Factor requirement
If the Displacement result shows high displacement, consider running a Nonlinear study to gain more insight Check other results
Examine the Below target Result visualization to see where the weakest areas are
Check the stress result to see if, and where, the material might yield
Check the displacement result to see how far from its original alignment the model has moved
Look at other results, such as reaction forces to check your study set up, or strain to check your material performance Lightweight the design
Set a Safety Factor upper limit to find where material can be removed
Remove material from areas that exceed the Safety Factor upper limit
Generate alternative designs In the Generative Design workspace, create design modifications Remove unnecessary material using a Shape Optimization study

## Load Case3 - Results

Result Summary
Result type | Sub-result | Minimum | Maximum
Safety Factor
| Safety Factor | 1,576.748 | 976,624.625
Stress
Von Mises | 4.095E-05 MPa | 0.025 MPa
1st Principal | −0.001 MPa | 0.043 MPa
3rd Principal | −0.009 MPa | 0.016 MPa
Normal XX | −0.008 MPa | 0.019 MPa
Normal YY | −0.007 MPa | 0.019 MPa
Normal ZZ | −0.005 MPa | 0.041 MPa
Shear XY | −0.002 MPa | 0.002 MPa
Shear YZ | −0.009 MPa | 0.007 MPa
Shear XZ | −0.008 MPa | 0.011 MPa
Displacement
Total | 0 mm | 2.443E-04 mm
X | −2.442E-05 mm | 2.555E-05 mm
Y | −2.634E-05 mm | 2.446E-05 mm
Z | 0 mm | 2.442E-04 mm
Reaction Force
Total | 0 N | 0.111 N
X | −0.031 N | 0.031 N
Y | −0.026 N | 0.024 N
Z | −0.105 N | 0 N
Strain
Equivalent | 1.532E-08 | 1.364E-05
1st Principal | 1.375E-08 | 1.501E-05
3rd Principal | −7.124E-06 | −8.604E-09
Normal XX | −3.032E-06 | 2.86E-06
Normal YY | −3.458E-06 | 2.873E-06
Normal ZZ | −1.06E-06 | 9.824E-06
Shear XY | −2.369E-06 | 2.318E-06
Shear YZ | −8.398E-06 | 7.205E-06
Shear XZ | −7.466E-06 | 1.066E-05
Contact Pressure
Total | 0 MPa | 0.04 MPa
X | −0.007 MPa | 0.007 MPa
Y | −0.007 MPa | 0.008 MPa
Z | −0.038 MPa | 0.005 MPa
Contact Force
Total | 0 N | 0.012 N
X | −0.008 N | 0.009 N
Y | −0.012 N | 0.012 N
Z | −0.007 N | 0.005 N

Safety Factor
Safety Factor


Stress
Von Mises

1st Principal

3rd Principal


Displacement
Total

## Load Case4

Constraints
Fixed5
Type | Fixed
Ux | Fixed
Uy | Fixed
Uz | Fixed

Loads
Linear Global Load4


Type | Linear Global Load
Acceleration
X Value | 0.00 m / s^2
Y Value | 0.00 m / s^2
Z Value | 49.00 m / s^2

## Load Case4 - Guided Results

Above Safety Factor Limit

With the analysis criteria in this study setup, there is opportunity to reduce the volume of material and cost of this design.

Next Steps

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

## Load Case4 - Results

Result Summary
Result type | Sub-result | Minimum | Maximum
| Safety Factor | 946.048 | 585,974.75
Stress
Von Mises | 6.825E-05 MPa | 0.042 MPa
1st Principal | −0.002 MPa | 0.072 MPa
3rd Principal | −0.015 MPa | 0.027 MPa
Normal XX | −0.013 MPa | 0.032 MPa
Normal YY | −0.012 MPa | 0.032 MPa
Normal ZZ | −0.008 MPa | 0.069 MPa
Shear XY | −0.004 MPa | 0.004 MPa
Shear YZ | −0.014 MPa | 0.012 MPa
Shear XZ | −0.013 MPa | 0.018 MPa
Total | 0 mm | 4.071E-04 mm
X | −4.071E-05 mm | 4.259E-05 mm
Y | −4.39E-05 mm | 4.077E-05 mm
Z | 0 mm | 4.07E-04 mm
Reaction Force
Total | 0 N | 0.185 N
X | −0.052 N | 0.051 N
Y | −0.043 N | 0.041 N
Z | −0.174 N | 0 N
Strain
Equivalent | 2.554E-08 | 2.273E-05
1st Principal | 2.292E-08 | 2.502E-05
3rd Principal | −1.187E-05 | −1.434E-08
Normal XX | −5.053E-06 | 4.767E-06
Normal YY | −5.763E-06 | 4.788E-06
Normal ZZ | −1.766E-06 | 1.637E-05
Shear XY | −3.948E-06 | 3.864E-06
Shear YZ | −1.40E-05 | 1.201E-05
Shear XZ | −1.244E-05 | 1.777E-05
Contact Pressure
Total | 0 MPa | 0.066 MPa
X | −0.012 MPa | 0.012 MPa
Y | −0.011 MPa | 0.013 MPa
Z | −0.064 MPa | 0.008 MPa
Contact Force
Total | 0 N | 0.02 N
X | −0.014 N | 0.015 N
Y | −0.02 N | 0.02 N
Z | −0.011 N | 0.008 N

Safety Factor
Safety Factor

Stress
Von Mises

1st Principal


3rd Principal

Displacement
Total

## Load Case5

Constraints
Fixed6
Type | Fixed
Ux | Fixed
Uy | Fixed
Uz | Fixed

Loads
Linear Global Load5
Type | Linear Global Load
Acceleration
X Value | 0.00 m / s^2
Y Value | 0.00 m / s^2
Z Value | 58.80 m / s^2

## Load Case5 - Guided Results

Safety Factor

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

Next Steps

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

## Load Case5 - Results

Result Summary
Result type | Sub-result | Minimum | Maximum
Safety Factor
| Safety Factor | 788.374 | 488,312.313
Stress
Von Mises | 8.19E-05 MPa | 0.051 MPa
1st Principal | −0.002 MPa | 0.086 MPa
3rd Principal | −0.018 MPa | 0.033 MPa
Normal XX | −0.016 MPa | 0.038 MPa
Normal YY | −0.014 MPa | 0.038 MPa
Normal ZZ | −0.01 MPa | 0.082 MPa
Shear XY | −0.005 MPa | 0.005 MPa
Shear YZ | −0.017 MPa | 0.015 MPa
Shear XZ | −0.015 MPa | 0.022 MPa
Displacement
Total | 0 mm | 4.885E-04 mm
X | −4.885E-05 mm | 5.111E-05 mm
Y | −5.268E-05 mm | 4.892E-05 mm
Z | 0 mm | 4.884E-04 mm
Reaction Force
Total | 0 N | 0.222 N
X | −0.062 N | 0.061 N
Y | −0.052 N | 0.049 N
Z | −0.209 N | 0 N
Strain
Equivalent | 3.065E-08 | 2.727E-05
1st Principal | 2.751E-08 | 3.002E-05
3rd Principal | −1.425E-05 | −1.721E-08
Normal XX | −6.063E-06 | 5.72E-06
Normal YY | −6.916E-06 | 5.746E-06
Normal ZZ | −2.12E-06 | 1.965E-05
Shear XY | −4.738E-06 | 4.637E-06
Shear YZ | −1.68E-05 | 1.441E-05
Shear XZ | −1.493E-05 | 2.132E-05
Contact Pressure
Total | 0 MPa | 0.079 MPa
X | −0.015 MPa | 0.014 MPa
Y | −0.014 MPa | 0.015 MPa
Z | −0.077 MPa | 0.01 MPa
Contact Force
Total | 0 N | 0.024 N
X | −0.017 N | 0.018 N
Y | −0.024 N | 0.024 N
Z | −0.014 N | 0.009 N

Safety Factor
Safety Factor

Stress
Von Mises


1st Principal

3rd Principal

Displacement
Total


## Load Case6

Constraints
Fixed8
Type | Fixed
Ux | Fixed
Uy | Fixed
Uz | Fixed

Loads
Linear Global Load7

Type | Linear Global Load
Acceleration
X Value | 0.00 m / s^2
Y Value | 0.00 m / s^2
Z Value | 78.40 m / s^2

## Load Case6 - Guided Results

With the analysis criteria in this study setup, the design is expected to bend permanently or break.

Next Steps

Below Safety Factor Target

Strengthen weak areas
Add more material to weak areas
Select a material with a higher yield strength Stiffen the design
Modify the shape with a Generative Design study Generate alternative designs Add more material to weak areas
Select a material with a higher yield strength Stiffen the design
Modify the shape with a Generative Design study Above Safety Factor Limit
Validate your study setup
Check the loads are not set too high
Check the mesh refinement and consider increasing it in areas of high stress
Confirm your Safety Factor requirement
If the Displacement result shows high displacement, consider running a Nonlinear study to gain more insight Check other results
Examine the Below target Result visualization to see where the weakest areas are
Check the stress result to see if, and where, the material might yield
Check the displacement result to see how far from its original alignment the model has moved
Look at other results, such as reaction forces to check your study set up, or strain to check your material performance Lightweight the design
Set a Safety Factor upper limit to find where material can be removed
Remove material from areas that exceed the Safety Factor upper limit
Generate alternative designs In the Generative Design workspace, create design modifications Remove unnecessary material using a Shape Optimization study

## Load Case6 - Results

Result Summary
Result type | Sub-result | Minimum | Maximum
Safety Factor
| Safety Factor | 591.28 | 366,234.281
Stress
Von Mises | 1.092E-04 MPa | 0.068 MPa
1st Principal | −0.003 MPa | 0.115 MPa
3rd Principal | −0.024 MPa | 0.044 MPa
Normal XX | −0.021 MPa | 0.051 MPa
Normal YY | −0.019 MPa | 0.051 MPa
Normal ZZ | −0.013 MPa | 0.11 MPa
Shear XY | −0.006 MPa | 0.006 MPa
Shear YZ | −0.023 MPa | 0.02 MPa
Shear XZ | −0.021 MPa | 0.029 MPa
Displacement
Total | 0 mm | 6.513E-04 mm
X | −6.513E-05 mm | 6.814E-05 mm
Y | −7.025E-05 mm | 6.523E-05 mm
Z | 0 mm | 6.512E-04 mm
Reaction Force
Total | 0 N | 0.296 N
X | −0.083 N | 0.082 N
Y | −0.069 N | 0.065 N
Z | −0.279 N | 0 N
Strain
Equivalent | 4.087E-08 | 3.636E-05
1st Principal | 3.668E-08 | 4.003E-05
3rd Principal | −1.90E-05 | −2.294E-08
Normal XX | −8.084E-06 | 7.627E-06
Normal YY | −9.221E-06 | 7.661E-06
Normal ZZ | −2.826E-06 | 2.62E-05
Shear XY | −6.317E-06 | 6.182E-06
Shear YZ | −2.24E-05 | 1.921E-05
Shear XZ | −1.991E-05 | 2.843E-05
Contact Pressure
Total | 0 MPa | 0.106 MPa
X | −0.02 MPa | 0.019 MPa
Y | −0.018 MPa | 0.02 MPa
Z | −0.103 MPa | 0.013 MPa
Contact Force
Total | 0 N | 0.033 N
X | −0.022 N | 0.023 N
Y | −0.032 N | 0.032 N
Z | −0.018 N | 0.012 N

Safety Factor
Safety Factor

Stress
Von Mises


1st Principal

3rd Principal

Displacement
Total


## Load Case7

Constraints
Fixed9
Type | Fixed
Ux | Fixed
Uy | Fixed
Uz | Fixed

Loads
Linear Global Load8
Type | Linear Global Load
Acceleration
X Value | 0.00 m / s^2
Y Value | 0.00 m / s^2
Z Value | 98.00 m / s^2

## Load Case7 - Guided Results

Safety Factor

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

Next Steps

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

## Load Case7 - Results

Result Summary
Result type | Sub-result | Minimum | Maximum
Safety Factor
| Safety Factor | 473.024 | 292,987.375
Stress
Von Mises | 1.365E-04 MPa | 0.085 MPa
1st Principal | −0.004 MPa | 0.144 MPa
3rd Principal | −0.03 MPa | 0.055 MPa
Normal XX | −0.026 MPa | 0.063 MPa
Normal YY | −0.024 MPa | 0.064 MPa
Normal ZZ | −0.016 MPa | 0.137 MPa
Shear XY | −0.008 MPa | 0.008 MPa
Shear YZ | −0.029 MPa | 0.025 MPa
Shear XZ | −0.026 MPa | 0.037 MPa
Displacement
Total | 0 mm | 8.142E-04 mm
X | −8.141E-05 mm | 8.518E-05 mm
Y | −8.781E-05 mm | 8.154E-05 mm
Z | 0 mm | 8.141E-04 mm
Reaction Force
Total | 0 N | 0.37 N
X | −0.103 N | 0.102 N
Y | −0.086 N | 0.081 N
Z | −0.349 N | 0 N
Strain
Equivalent | 5.108E-08 | 4.545E-05
1st Principal | 4.585E-08 | 5.004E-05
3rd Principal | −2.375E-05 | −2.868E-08
Normal XX | −1.011E-05 | 9.534E-06
Normal YY | −1.153E-05 | 9.577E-06
Normal ZZ | −3.533E-06 | 3.275E-05
Shear XY | −7.896E-06 | 7.728E-06
Shear YZ | −2.799E-05 | 2.402E-05
Shear XZ | −2.489E-05 | 3.554E-05
Contact Pressure
Total | 0 MPa | 0.132 MPa
X | −0.025 MPa | 0.024 MPa
Y | −0.023 MPa | 0.025 MPa
Z | −0.128 MPa | 0.017 MPa
Contact Force
Total | 0 N | 0.041 N
X | −0.028 N | 0.029 N
Y | −0.04 N | 0.04 N
Z | −0.023 N | 0.015 N

Safety Factor
Safety Factor


Stress
Von Mises

1st Principal

3rd Principal


Total

## Load Case8

Constraints
Fixed10


Type | Fixed
Ux | Fixed
Uy | Fixed
Uz | Fixed

Loads
Linear Global Load9


Type | Linear Global Load
Acceleration
X Value | 0.00 m / s^2
Y Value | 0.00 m / s^2
Z Value | 147.00 m / s^2

## Load Case8 - Guided Results

Safety Factor

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

Next Steps

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

## Load Case8 - Results

Result Summary
Result type | Sub-result | Minimum | Maximum
Safety Factor
| Safety Factor | 315.349 | 195,324.953
Stress
Von Mises | 2.048E-04 MPa | 0.127 MPa
1st Principal | −0.006 MPa | 0.216 MPa
3rd Principal | −0.045 MPa | 0.082 MPa
Normal XX | −0.04 MPa | 0.095 MPa
Normal YY | −0.036 MPa | 0.096 MPa
Normal ZZ | −0.024 MPa | 0.206 MPa
Shear XY | −0.012 MPa | 0.012 MPa
Shear YZ | −0.043 MPa | 0.037 MPa
Shear XZ | −0.038 MPa | 0.055 MPa
Displacement
Total | 0 mm | 0.001 mm
X | −1.221E-04 mm | 1.278E-04 mm
Y | −1.317E-04 mm | 1.223E-04 mm
Z | 0 mm | 0.001 mm
Reaction Force
Total | 0 N | 0.555 N
X | −0.155 N | 0.153 N
Y | −0.13 N | 0.122 N
Z | −0.523 N | 0 N
Strain
Equivalent | 7.662E-08 | 6.818E-05
1st Principal | 6.877E-08 | 7.506E-05
3rd Principal | −3.562E-05 | −4.302E-08
Normal XX | −1.516E-05 | 1.43E-05
Normal YY | −1.729E-05 | 1.437E-05
Normal ZZ | −5.299E-06 | 4.912E-05
Shear XY | −1.184E-05 | 1.159E-05
Shear YZ | −4.199E-05 | 3.602E-05
Shear XZ | −3.733E-05 | 5.331E-05
Contact Pressure
Total | 0 MPa | 0.198 MPa
X | −0.037 MPa | 0.035 MPa
Y | −0.034 MPa | 0.038 MPa
Z | −0.193 MPa | 0.025 MPa
Contact Force
Total | 0 N | 0.061 N
X | −0.042 N | 0.044 N
Y | −0.06 N | 0.059 N
Z | −0.035 N | 0.023 N

Safety Factor
Safety Factor


Stress
Von Mises


1st Principal


3rd Principal


Displacement
Total


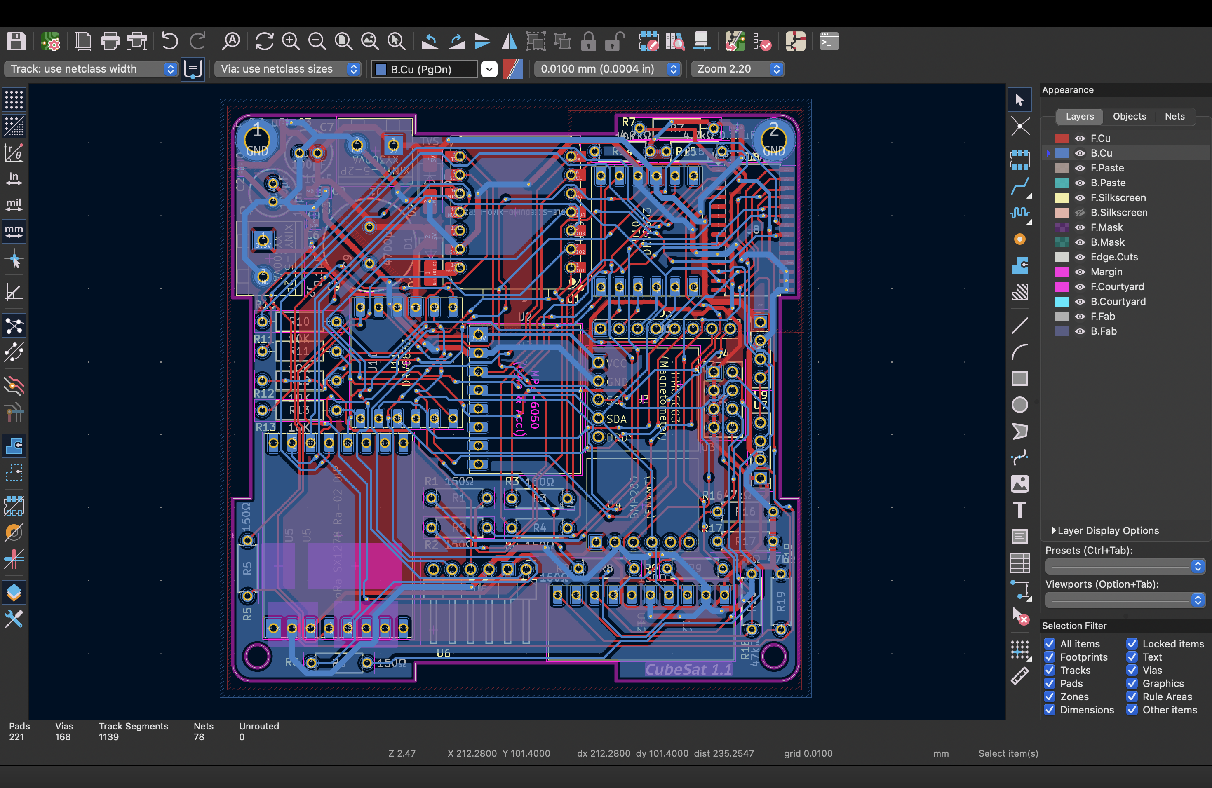
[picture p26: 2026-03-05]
CubeSat V1.1/PCB Design/CubeSat_PCBKiCAD_BackCopper.png

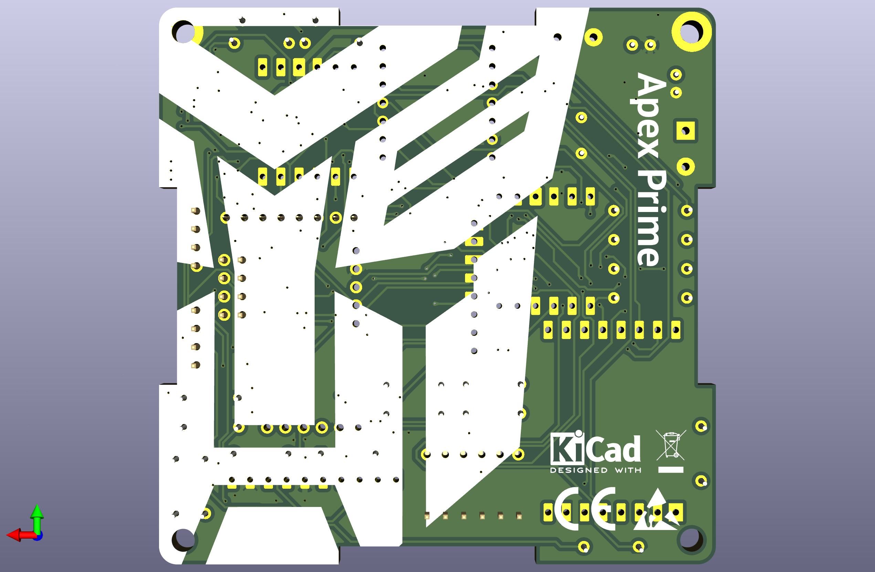
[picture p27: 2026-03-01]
CubeSat V1.1/PCB Design/CubeSat_3D_BackView.png

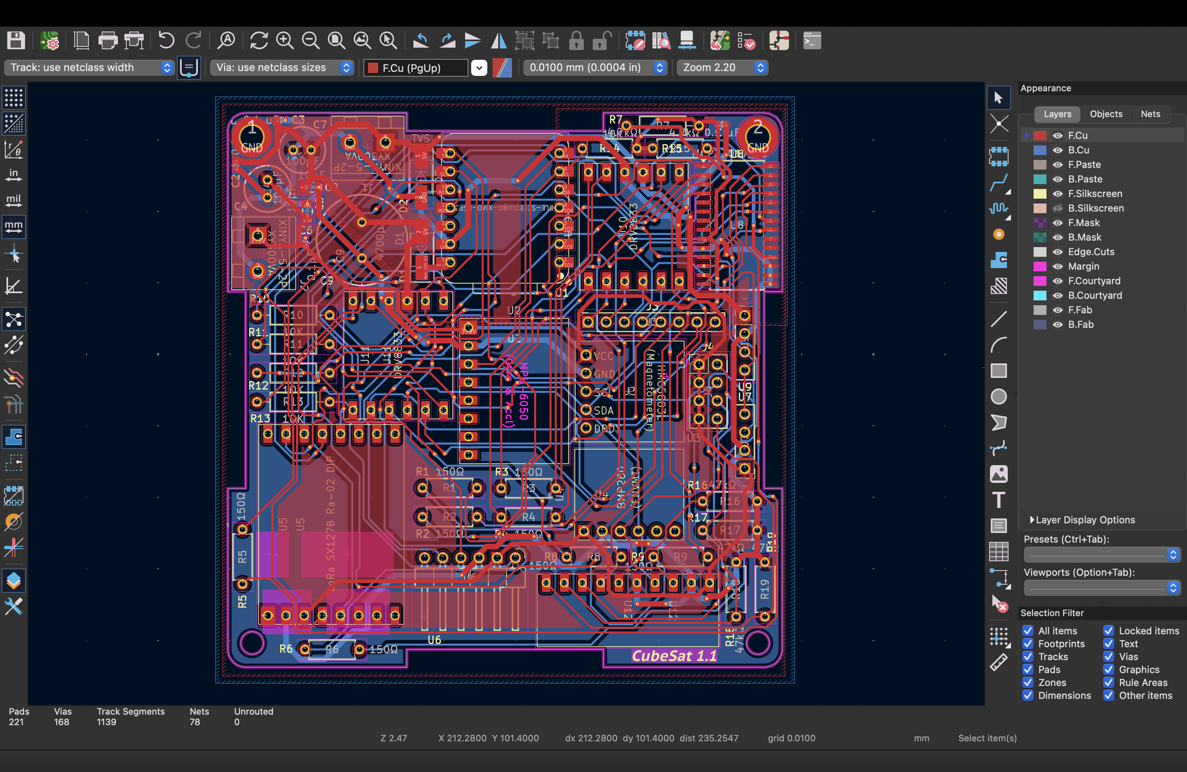
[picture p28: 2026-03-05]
CubeSat V1.1/PCB Design/CubeSat_PCBKiCAD_FrontCopper.png

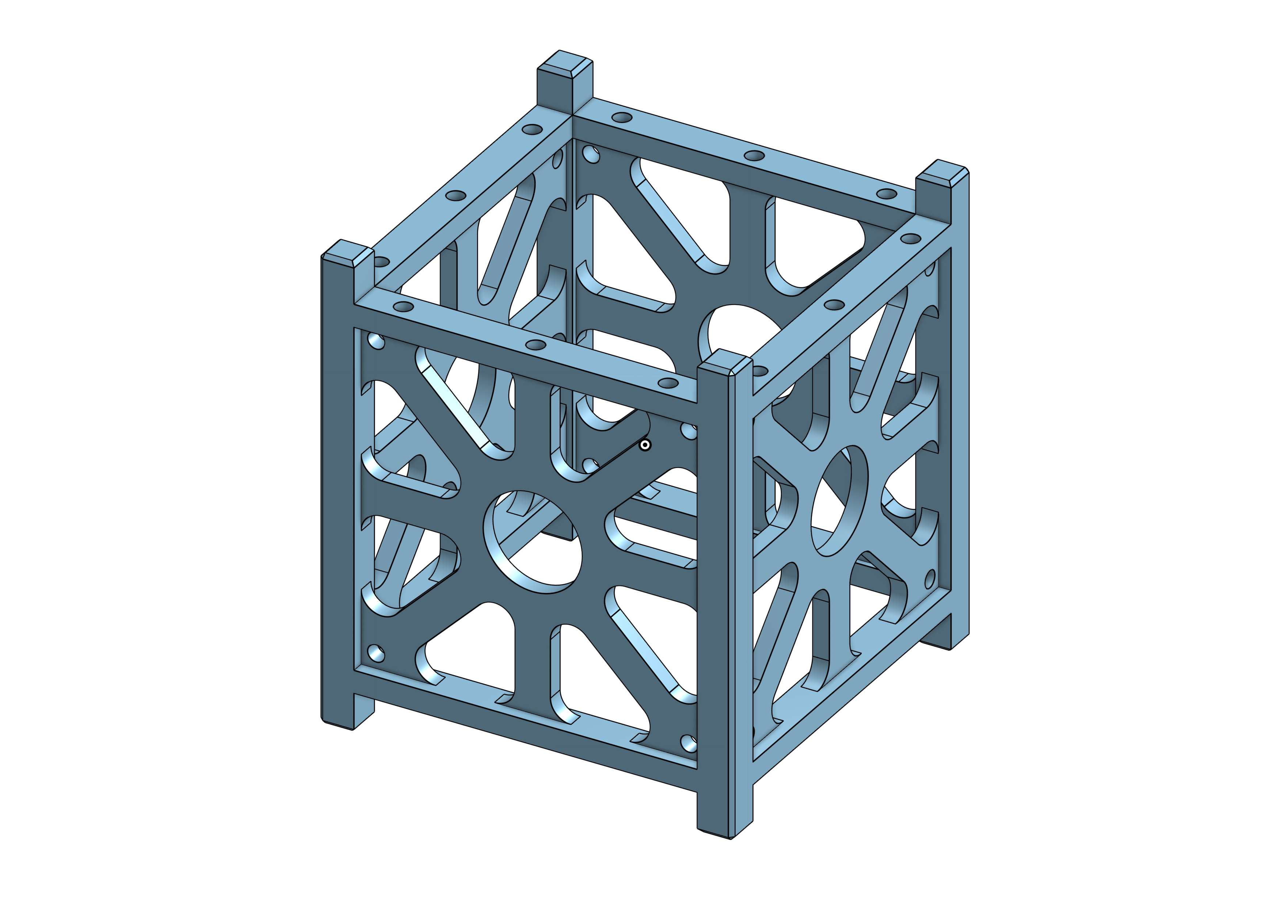
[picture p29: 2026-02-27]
CubeSat V1.1/CAD Model/CubeSat1.png

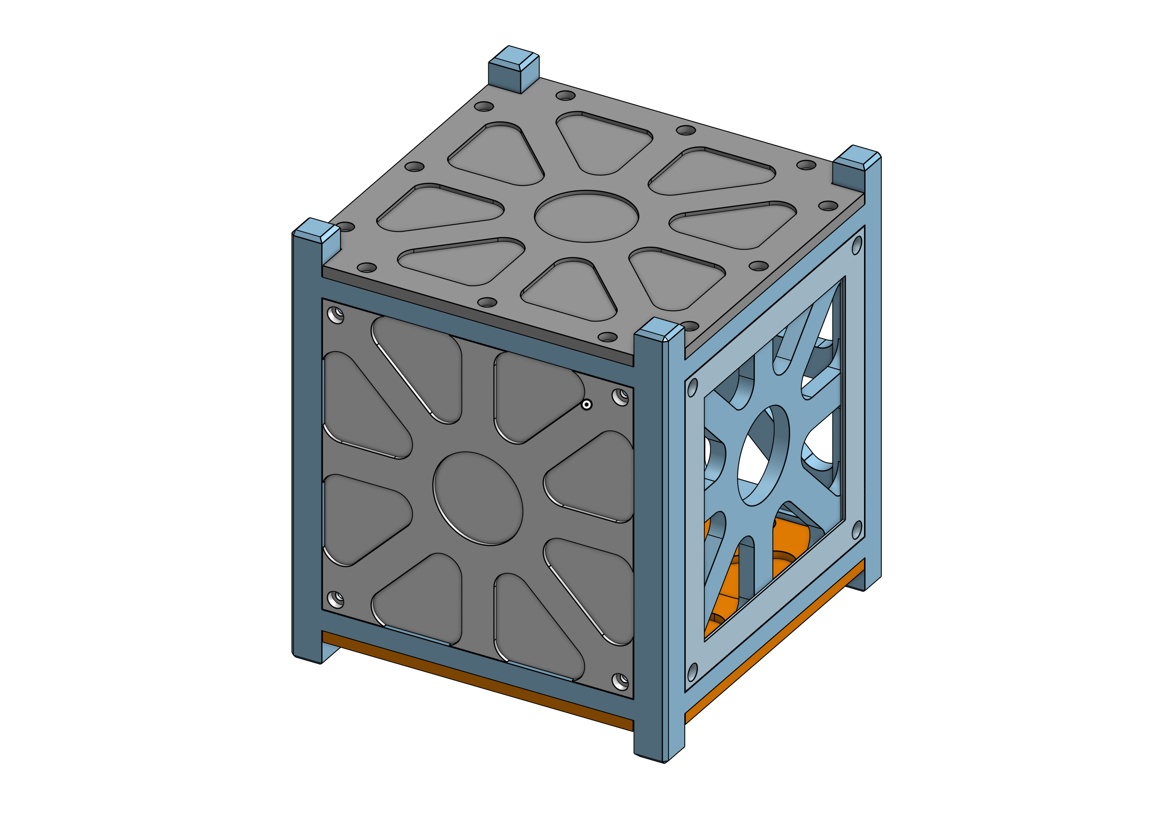
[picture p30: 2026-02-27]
CubeSat V1.1/CAD Model/CubeSat2.png

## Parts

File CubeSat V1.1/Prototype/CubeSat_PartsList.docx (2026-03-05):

PROJECT – K (CS)

S. No. | Component | Qty. | Price (Rs.) | W/B

Navigation, Control and Comms. Subsystem (NCCS)
1. | Microcontroller – XIAO ESP32 Sense | 1 | 1400 | RB
2. | MPU6050 | 1 | 165 | RC
3. | HMC5883L | 1 | 120 | RC
4. | AI-Thinker GP-02 GPS | 1 | 415 | TS
5. | BME280 Altimeter Sensor | 1 | 51 | RB
6. | SX1278 LoRa Module Ra- 02 433MHZ | 2 | 736 | RC
7. | 433MHz Antenna with UFL Connector | 2 | 98 | RC
| | | 1585

Electronics Power Subsystem (EPS)
7. | Solar Panel 70x70mm 0.65W | 3 | 168 | RC
8. | LDR Photoresistor | 3 | 21 | RB
9. | Solar Charging Module CN3065 | 1 | 106 | RB
10. | Schottky Diode 1N5822 | 6 | 36 | RB
11. | PTC Fuse MF-R075 | 2 | 40 | RB
12. | 3.7V LiPo 1500mAh Battery | 1 | 259 | RC
13. | CJMCU INA-219 Current, Voltage Sensor | 1 | 89 | RB
| | | 719

Attitude Determination and Control Subsystem (ADCS)
14. | Copper Wire | 100M | 520
15. | DRV8833 Motor Driver | 2 | 130 | RC
16. | Boost Converter

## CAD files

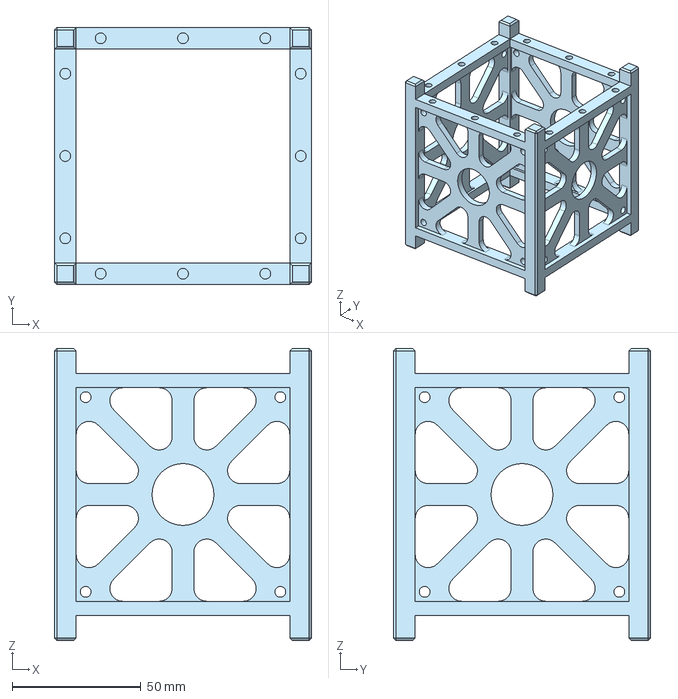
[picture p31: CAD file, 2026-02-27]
CubeSat V1.1/CAD Model/STEP Files/CubeSat Structure - Main Body.step
100.0 x 100.0 x 113.5 mm

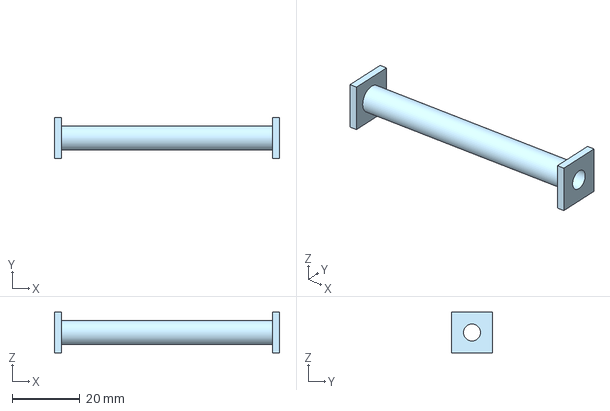
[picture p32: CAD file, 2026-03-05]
CubeSat V1.1/CAD Model/STEP Files/Magnetorquer-X,Y - Part 1.step
66.5 x 12.0 x 12.0 mm

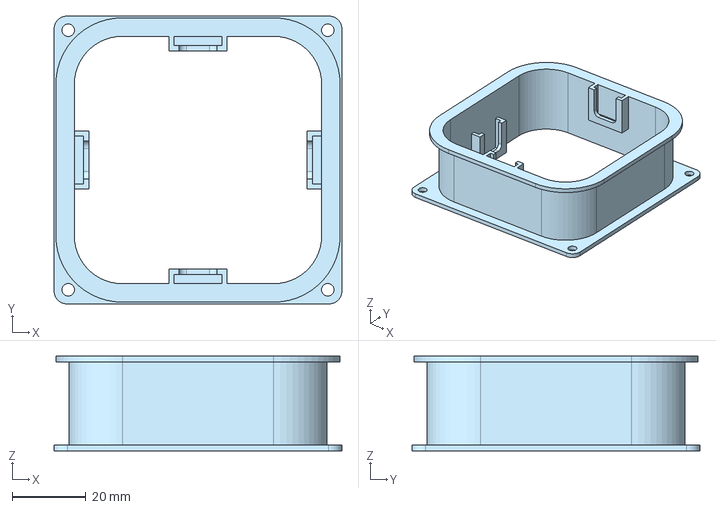
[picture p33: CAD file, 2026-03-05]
CubeSat V1.1/CAD Model/STEP Files/Magnetorquer-Z - Part 1.step
78.0 x 78.0 x 25.6 mm

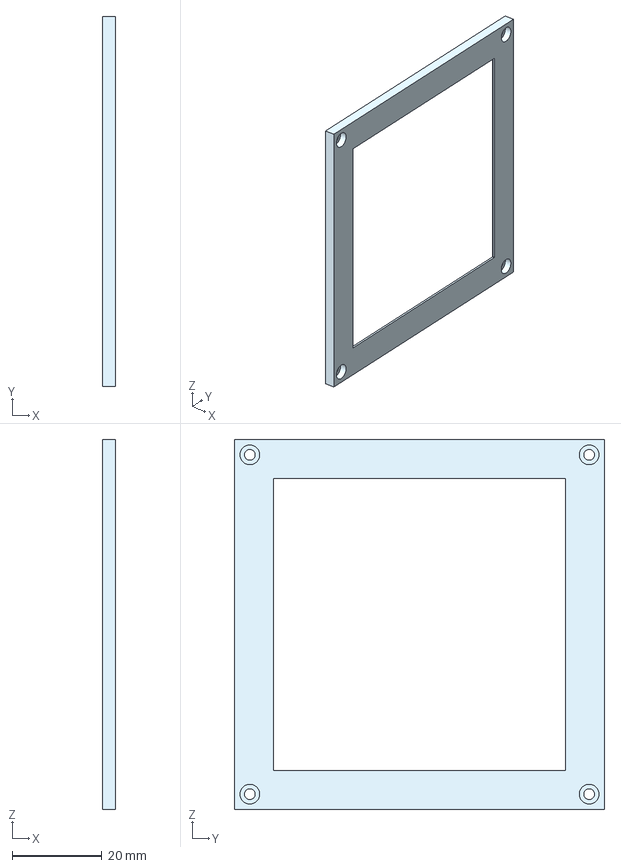
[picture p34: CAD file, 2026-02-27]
CubeSat V1.1/CAD Model/STEP Files/CubeSat Structure - Solar Plate.step
3.00 x 82.5 x 82.5 mm

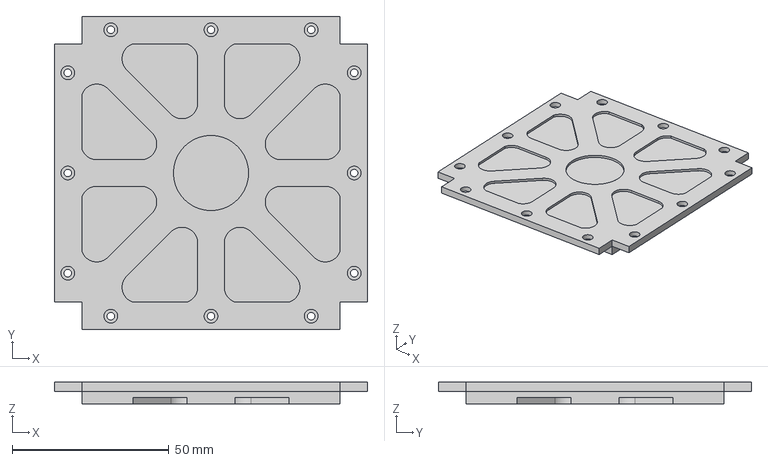
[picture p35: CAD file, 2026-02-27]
CubeSat V1.1/CAD Model/STEP Files/CubeSat Structure - Top Plate.step
100.0 x 100.0 x 7.00 mm

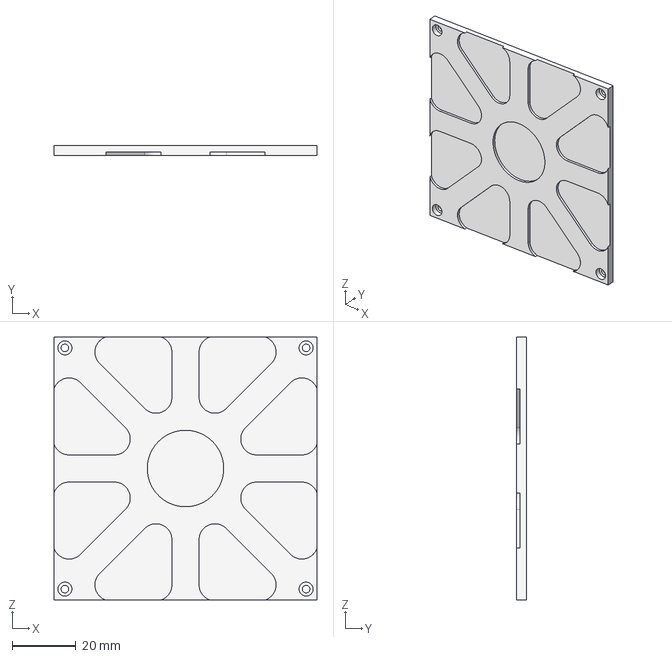
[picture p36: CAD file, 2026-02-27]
CubeSat V1.1/CAD Model/STEP Files/CubeSat Structure - Front Plate.step
82.5 x 3.00 x 82.5 mm

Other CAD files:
CubeSat V1.1/CAD Model/STEP Files/CubeSat Structure - Bottom Plate.step
CubeSat V1.1/CAD Model/STL Files/CubeSat Structure - Bottom Plate.stl
CubeSat V1.1/CAD Model/STL Files/CubeSat Structure - Front Plate.stl
CubeSat V1.1/CAD Model/STL Files/CubeSat Structure - Main Body.stl
CubeSat V1.1/CAD Model/STL Files/CubeSat Structure - Solar Plate.stl
CubeSat V1.1/CAD Model/STL Files/CubeSat Structure - Top Plate.stl
CubeSat V1.1/CAD Model/STL Files/Magnetorquer-X,Y - Part 1.stl
CubeSat V1.1/CAD Model/STL Files/Magnetorquer-Z - Part 1.stl

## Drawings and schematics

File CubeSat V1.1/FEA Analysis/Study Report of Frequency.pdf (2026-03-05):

# Study Report

## Simulation Model 1

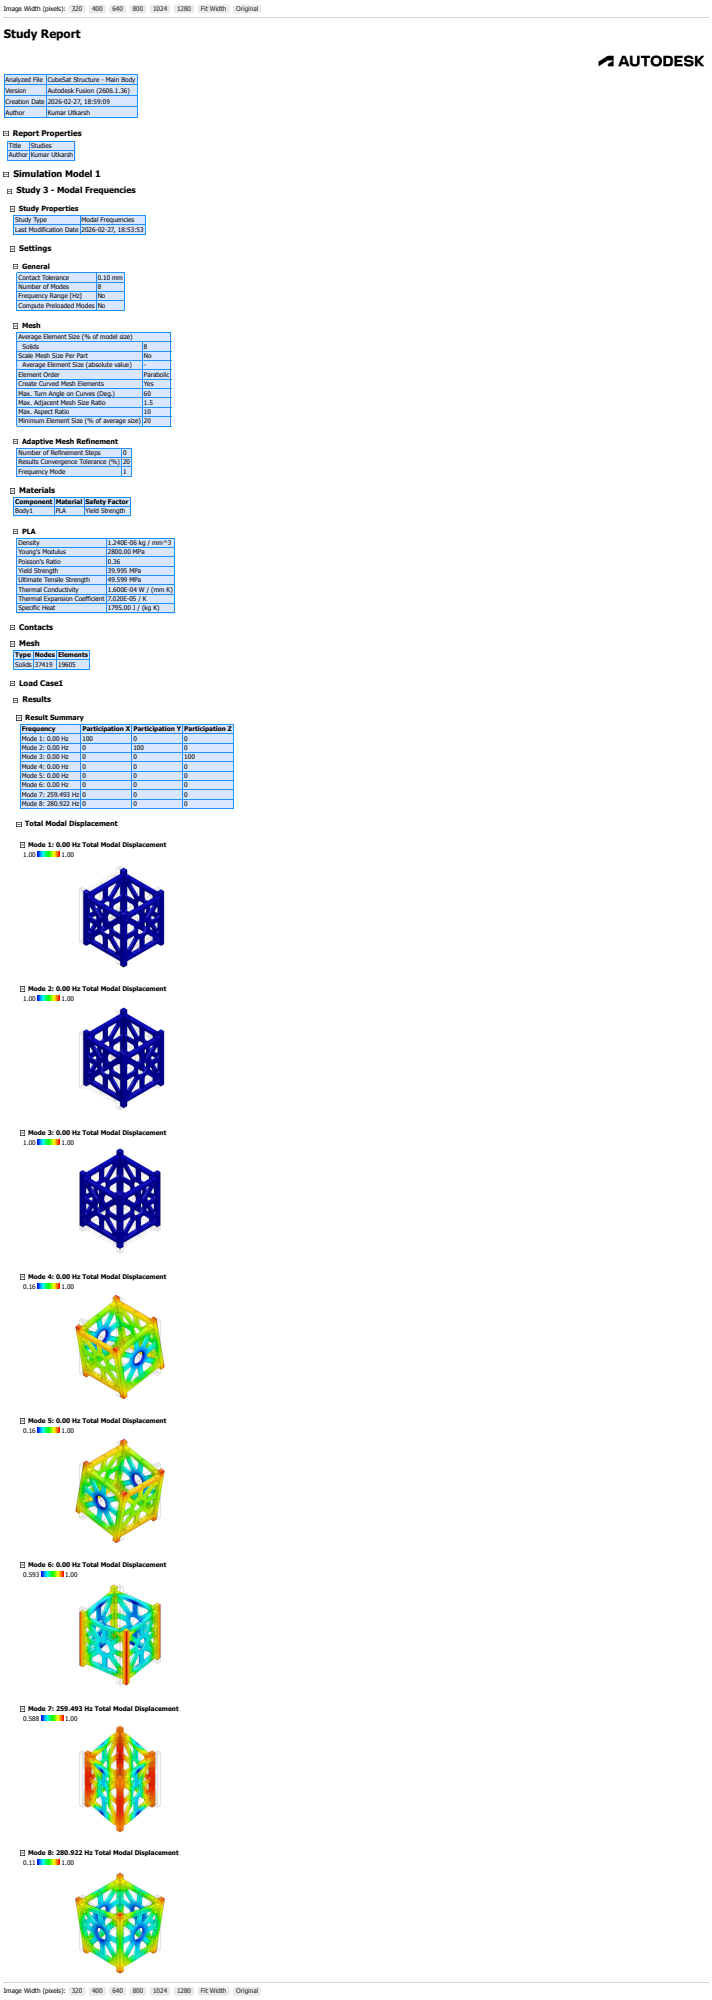
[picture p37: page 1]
Image Width (pixels): 320; Fit Width; Original; Report Properties; Study Properties; Settings; General; Materials; PLA; Contacts; Mesh; Load Case1; Results; Result Summary

Analyzed File | CubeSat Structure - Main Body
Version | Autodesk Fusion (2606.1.36)
Creation Date | 2026-02-27, 18:59:09
Author | Kumar Utkarsh

Title | Studies

Study 3 - Modal Frequencies

Study Type | Modal Frequencies
Last Modification Date | 2026-02-27, 18:53:53

Contact Tolerance | 0.10 mm
Number of Modes | 8
Frequency Range [Hz] | No
Compute Preloaded Modes | No

Mesh
Average Element Size (% of model size)

Solids | 8
Scale Mesh Size Per Part | No
Average Element Size (absolute value) | -
Element Order | Parabolic
Create Curved Mesh Elements | Yes
Max. Turn Angle on Curves (Deg.) | 60
Max. Adjacent Mesh Size Ratio | 1.5
Max. Aspect Ratio | 10
Minimum Element Size (% of average size) | 20

Adaptive Mesh Refinement

Number of Refinement Steps | 0
Results Convergence Tolerance (%) | 20
Frequency Mode | 1

Component | Material | Safety Factor
Body1 | PLA | Yield Strength

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

Type | Nodes | Elements
Solids | 37419 | 19605

Frequency | Participation X | Participation Y | Participation Z
Mode 1: 0.00 Hz | 100 | 0 | 0
Mode 2: 0.00 Hz | 0 | 100 | 0
Mode 3: 0.00 Hz | 0 | 0 | 100
Mode 4: 0.00 Hz | 0 | 0 | 0
Mode 5: 0.00 Hz | 0 | 0 | 0
Mode 6: 0.00 Hz | 0 | 0 | 0
Mode 7: 259.493 Hz | 0 | 0 | 0
Mode 8: 280.922 Hz | 0 | 0 | 0

Total Modal Displacement

Mode 1: 0.00 Hz Total Modal Displacement

Mode 2: 0.00 Hz Total Modal Displacement

Mode 3: 0.00 Hz Total Modal Displacement

Mode 4: 0.00 Hz Total Modal Displacement

Mode 5: 0.00 Hz Total Modal Displacement

Mode 6: 0.00 Hz Total Modal Displacement

Mode 7: 259.493 Hz Total Modal Displacement

Mode 8: 280.922 Hz Total Modal Displacement

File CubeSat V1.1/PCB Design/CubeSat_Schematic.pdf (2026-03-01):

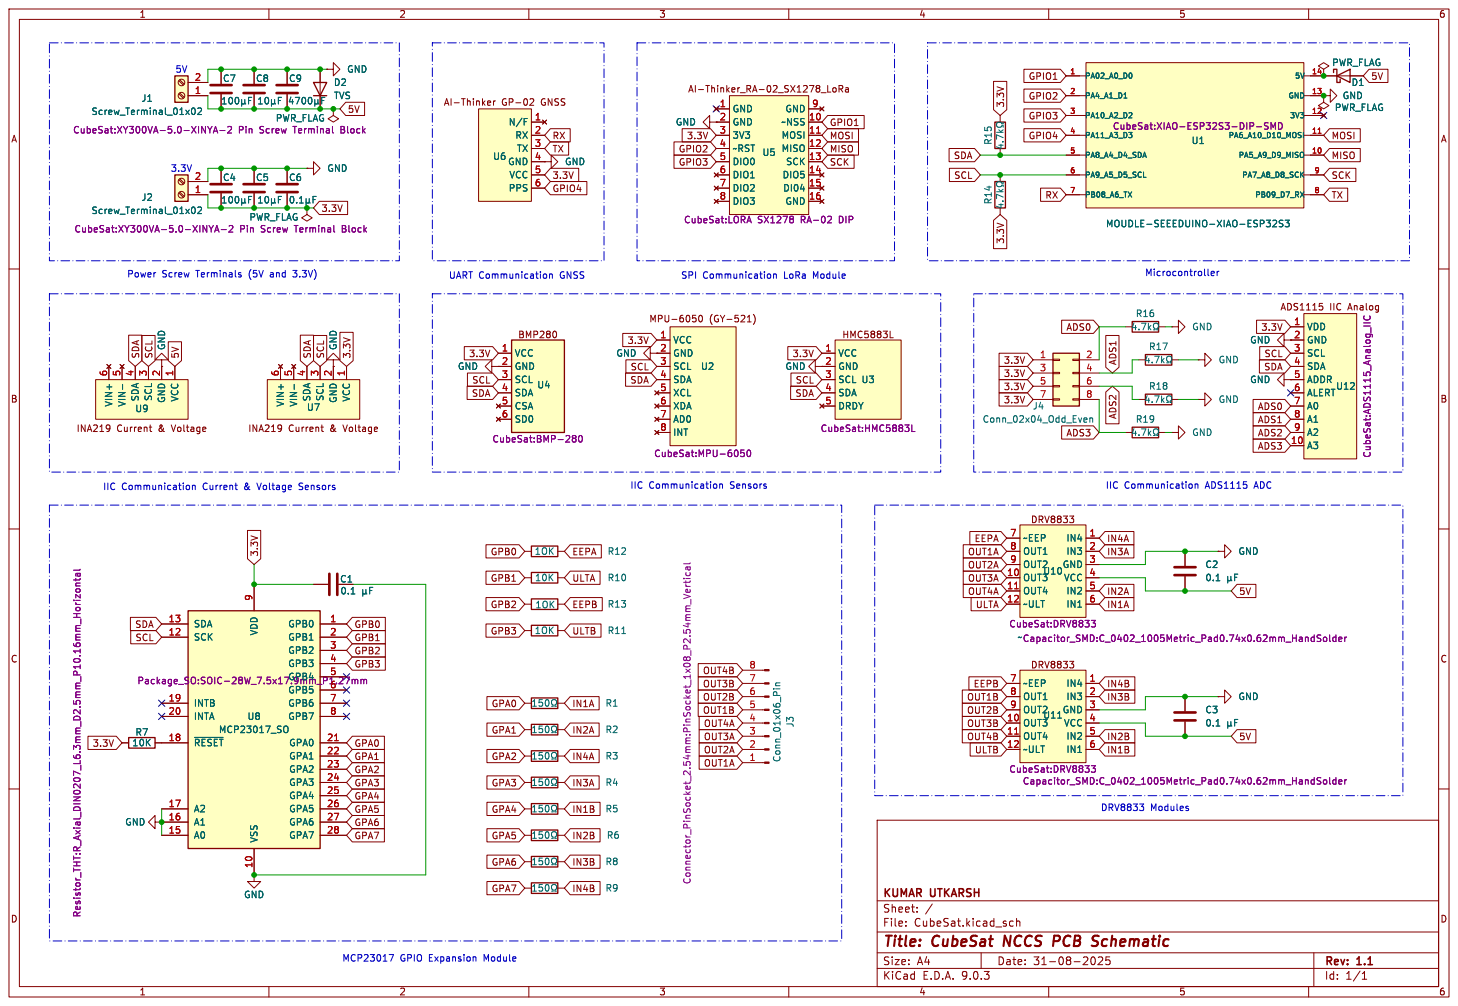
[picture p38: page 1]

3V3 12 U1 MOUDLE-SEEEDUINO-XIAO-ESP32S3 CubeSat:XIAO-ESP32S3-DIP-SMD
U1 MOUDLE-SEEEDUINO-XIAO-ESP32S3 CubeSat:XIAO-ESP32S3-DIP-SMD

U3 CubeSat:HMC5883L VCC 1 GND 2 SCL 3 SDA 4 DRDY 5 U2 CubeSat:MPU-6050 VCC 1 GND 2 SCL 3 SDA 4 XCL 5 XDA 6 AD0 7

File: CubeSat.kicad_sch Sheet: / KUMAR UTKARSH

Id: 1/1 Title: CubeSat NCCS PCB Schematic

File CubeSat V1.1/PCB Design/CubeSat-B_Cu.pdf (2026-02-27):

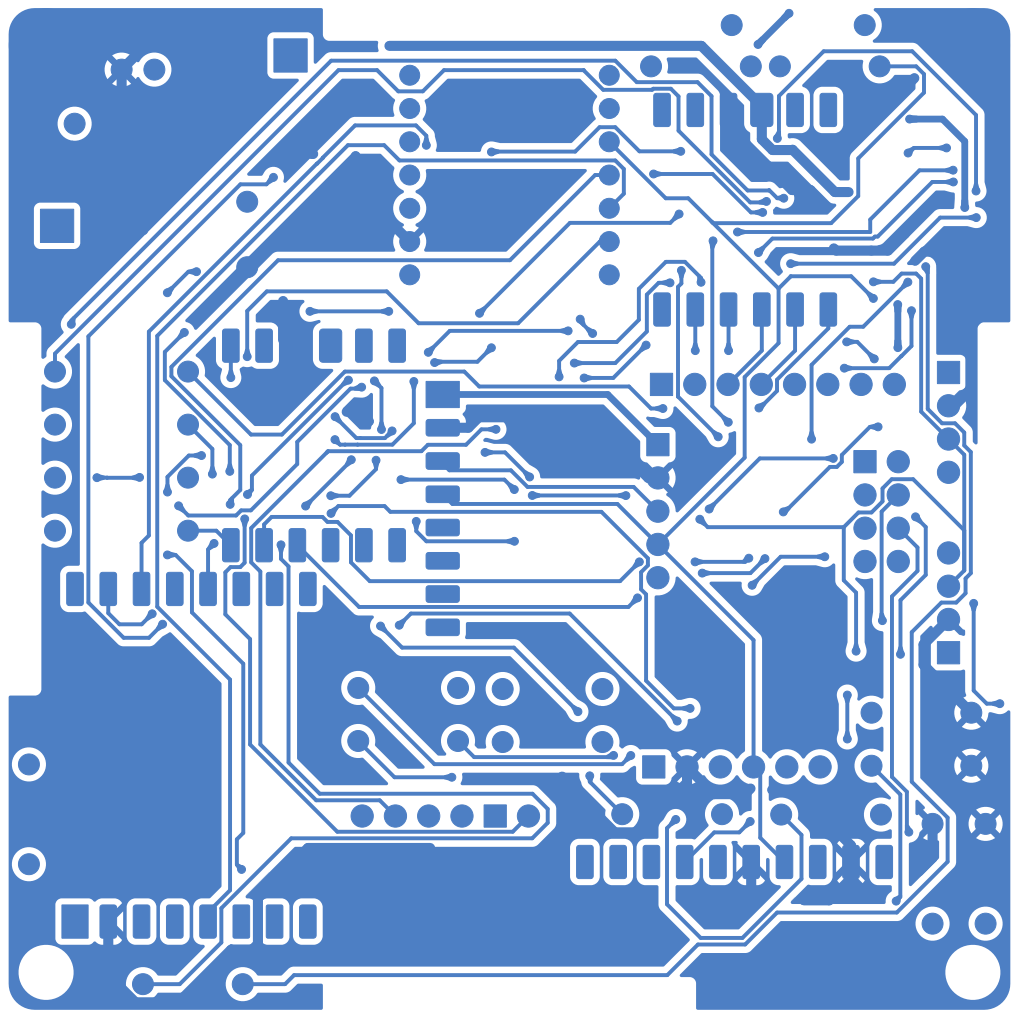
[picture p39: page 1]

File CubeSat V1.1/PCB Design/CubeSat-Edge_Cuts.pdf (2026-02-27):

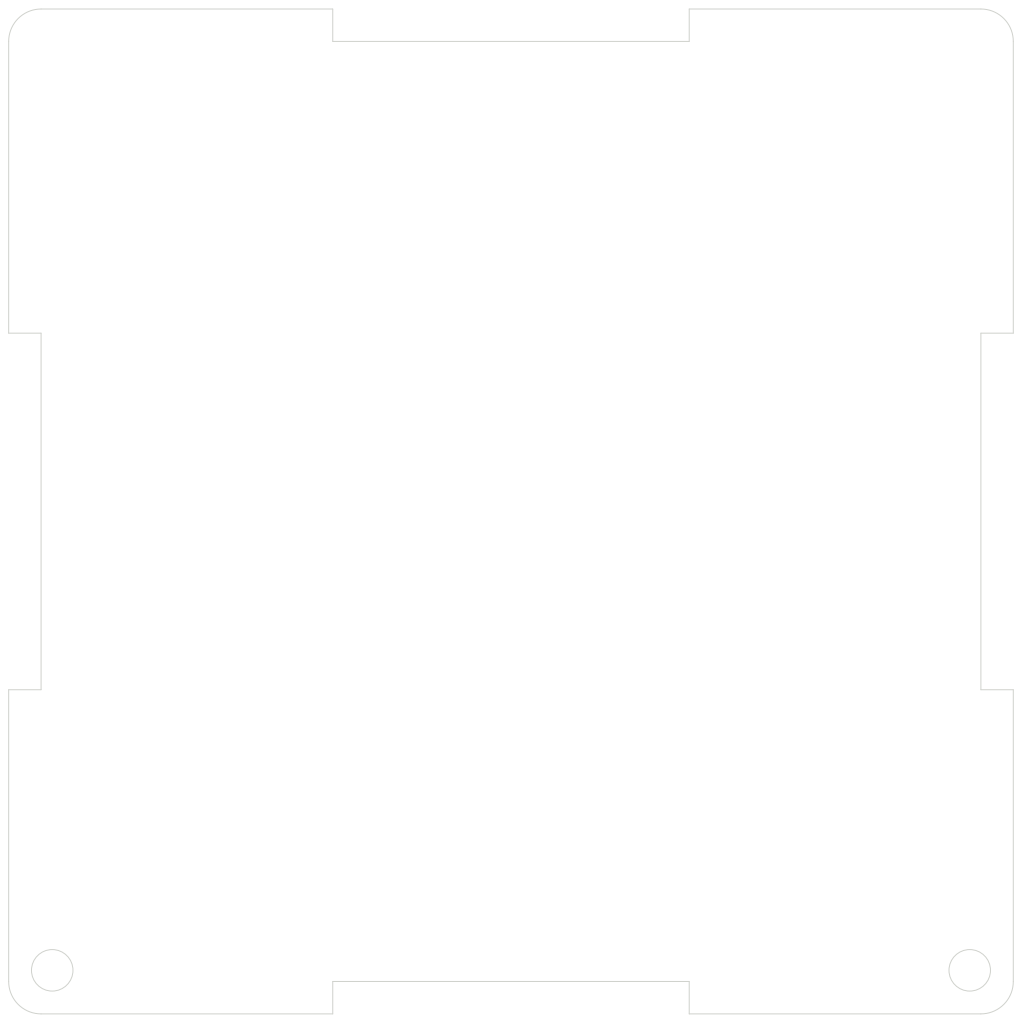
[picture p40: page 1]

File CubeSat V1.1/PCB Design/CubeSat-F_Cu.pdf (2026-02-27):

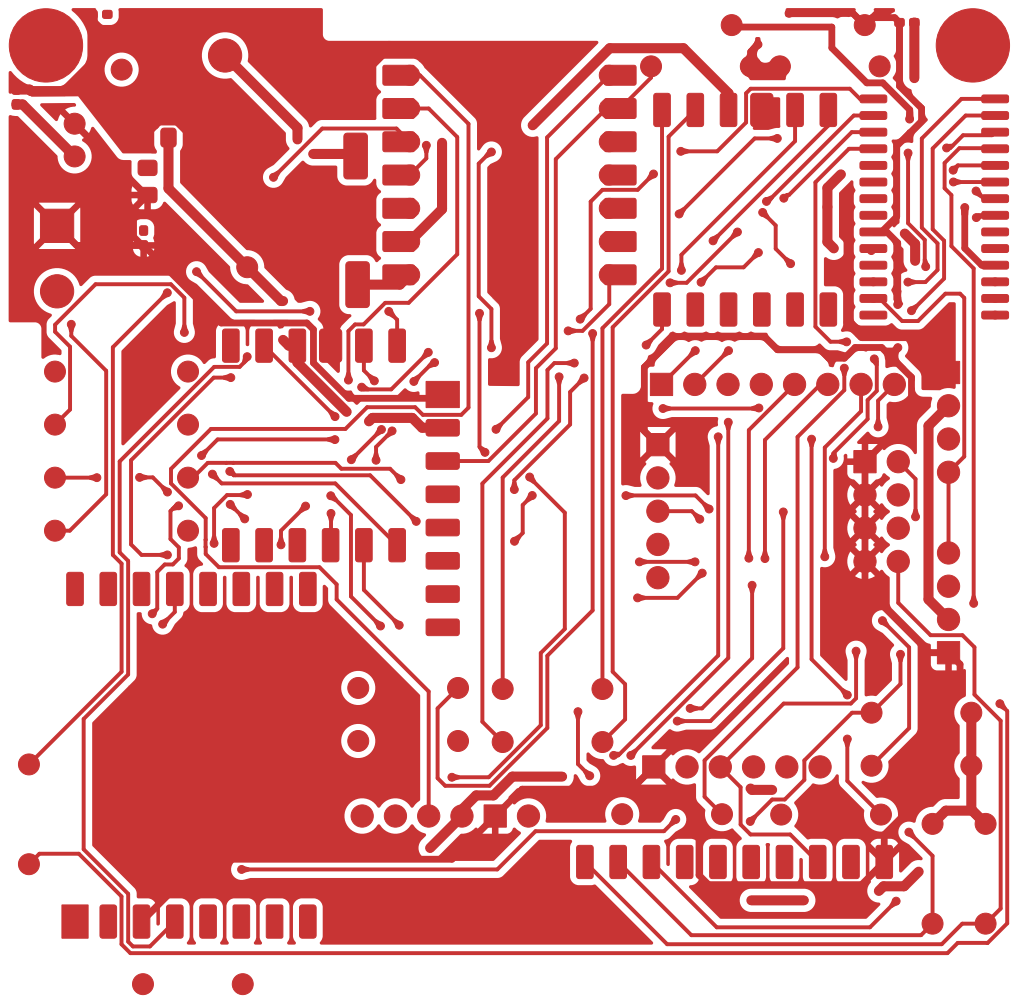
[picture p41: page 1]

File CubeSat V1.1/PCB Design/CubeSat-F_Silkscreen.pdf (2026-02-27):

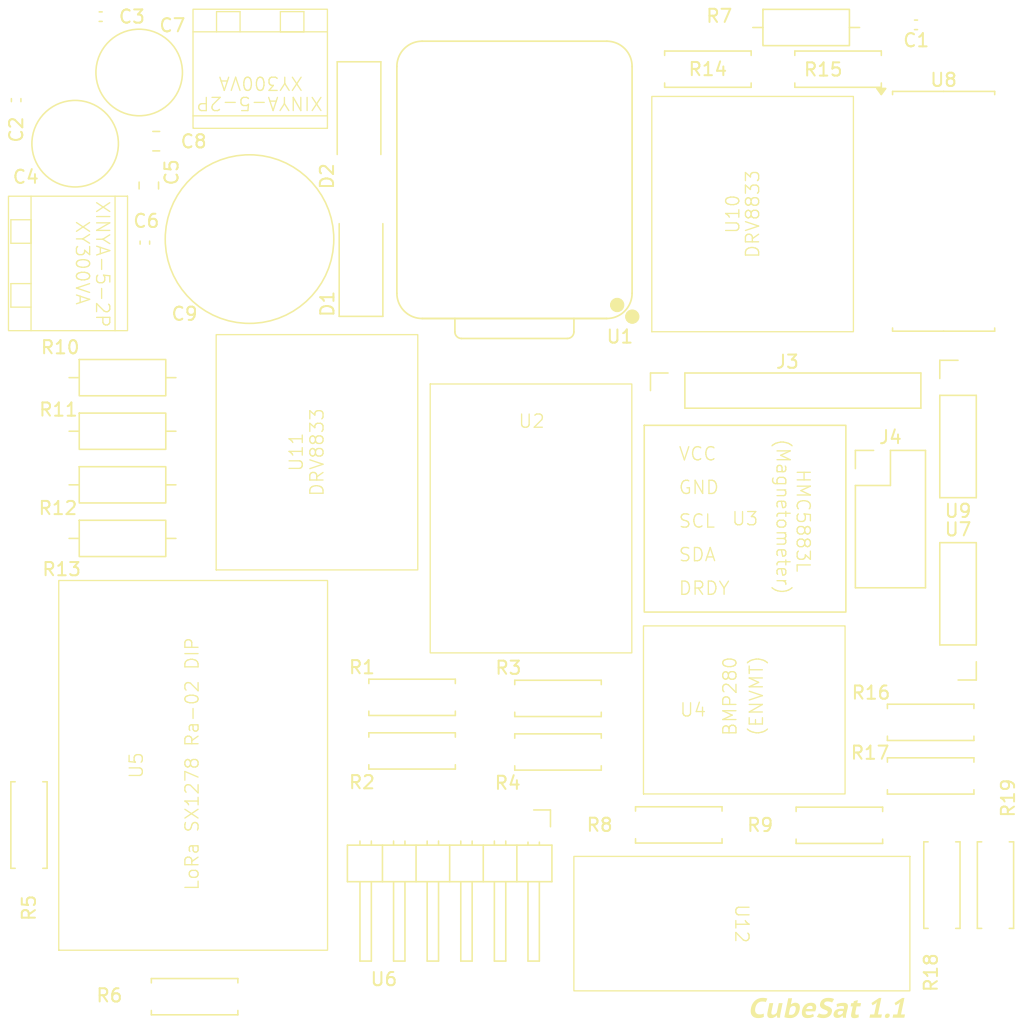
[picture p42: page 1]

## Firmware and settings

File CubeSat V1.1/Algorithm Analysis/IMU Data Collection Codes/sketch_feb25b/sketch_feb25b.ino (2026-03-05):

#include <Wire.h>
#include <Adafruit_MPU6050.h>
#include <Adafruit_Sensor.h>
#include <QMC5883LCompass.h>
#include <MadgwickAHRS.h>

#define SDA_PIN 5
#define SCL_PIN 6

#define LOOP_FREQ 200.0f
#define DT (1.0f / LOOP_FREQ)

Adafruit_MPU6050 mpu;
QMC5883LCompass compass;
Madgwick filter;

// ---------- Magnetometer Hard-Iron Offsets ----------
float magOffsetX = 0;
float magOffsetY = 0;
float magOffsetZ = 0;

// ---------- Gyro Bias ----------
float gyroBiasX = 0;
float gyroBiasY = 0;
float gyroBiasZ = 0;

// ---------- Magnetometer LPF ----------
float magX_f = 0;
float magY_f = 0;
float magZ_f = 0;
float magAlpha = 0.2f;

// ---------- Timing ----------
unsigned long lastMicros;

void calibrateGyro() {
  Serial.println("Calibrating Gyro...");
  float sumX = 0, sumY = 0, sumZ = 0;
  const int samples = 2000;

  for (int i = 0; i < samples; i++) {
    sensors_event_t a, g, t;
    mpu.getEvent(&a, &g, &t);

    sumX += g.gyro.x;
    sumY += g.gyro.y;
    sumZ += g.gyro.z;

    delay(2);
  }

  gyroBiasX = (sumX / samples) * 180.0 / PI;
  gyroBiasY = (sumY / samples) * 180.0 / PI;
  gyroBiasZ = (sumZ / samples) * 180.0 / PI;

  Serial.println("Gyro Calibration Done");
}

void setup() {

  Serial.begin(115200);
  Wire.begin(SDA_PIN, SCL_PIN);
  Wire.setClock(400000);

  if (!mpu.begin()) {
    Serial.println("MPU6050 not found!");
    while (1);
  }

  compass.init();

  mpu.setAccelerometerRange(MPU6050_RANGE_8_G);
  mpu.setGyroRange(MPU6050_RANGE_500_DEG);
  mpu.setFilterBandwidth(MPU6050_BAND_21_HZ);

  filter.begin(LOOP_FREQ);
  filter.beta = 0.06f;   // tuned for slow spacecraft motion

  delay(2000);
  calibrateGyro();

  lastMicros = micros();
}

void loop() {

  while ((micros() - lastMicros) < (1000000.0 / LOOP_FREQ));
  lastMicros = micros();

  sensors_event_t a, g, temp;
  mpu.getEvent(&a, &g, &temp);

  // -------- Accelerometer (g) --------
  float ax = a.acceleration.x / 9.81f;
  float ay = a.acceleration.y / 9.81f;
  float az = a.acceleration.z / 9.81f;

  // -------- Gyro (deg/s) --------
  float gx = (g.gyro.x * 180.0 / PI) - gyroBiasX;
  float gy = (g.gyro.y * 180.0 / PI) - gyroBiasY;
  float gz = (g.gyro.z * 180.0 / PI) - gyroBiasZ;

  // -------- Magnetometer --------
  compass.read();
  float mx = compass.getX() - magOffsetX;
  float my = compass.getY() - magOffsetY;
  float mz = compass.getZ() - magOffsetZ;

  // -------- LPF on Magnetometer --------
  magX_f = magAlpha * mx + (1 - magAlpha) * magX_f;
  magY_f = magAlpha * my + (1 - magAlpha) * magY_f;
  magZ_f = magAlpha * mz + (1 - magAlpha) * magZ_f;

  // -------- Update Madgwick --------
  filter.update(gx, gy, gz, ax, ay, az, magX_f, magY_f, magZ_f);

  // -------- Quaternion Output --------
  float q0 = filter.q0;
  float q1 = filter.q1;
  float q2 = filter.q2;
  float q3 = filter.q3;

  // Normalize for safety
  float norm = sqrt(q0*q0 + q1*q1 + q2*q2 + q3*q3);
  q0 /= norm; q1 /= norm; q2 /= norm; q3 /= norm;

  Serial.print("Q: ");
  Serial.print(q0,6); Serial.print(" ");
  Serial.print(q1,6); Serial.print(" ");
  Serial.print(q2,6); Serial.print(" ");
  Serial.println(q3,6);
}

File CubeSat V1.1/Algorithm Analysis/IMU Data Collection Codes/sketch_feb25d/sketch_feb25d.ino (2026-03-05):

#include <Wire.h>
#include <Adafruit_MPU6050.h>
#include <Adafruit_Sensor.h>
#include <QMC5883LCompass.h>
#include <MadgwickAHRS.h>

#define SDA_PIN 5
#define SCL_PIN 6

#define LOOP_FREQ 200.0f
#define DT (1.0f / LOOP_FREQ)

Adafruit_MPU6050 mpu;
QMC5883LCompass compass;
Madgwick filter;

// ======== GYRO BIAS (RAD/S) — FROM YOUR STATIONARY TEST ========
float gyroBiasX = -0.10695256f;
float gyroBiasY =  0.06276361f;
float gyroBiasZ =  0.00290245f;

// ======== MAG OFFSETS (Set after calibration if needed) ========
float magOffsetX = 0;
float magOffsetY = 0;
float magOffsetZ = 0;

// ======== TIMING ========
unsigned long lastMicros;

void setup() {

  Serial.begin(115200);

  Wire.begin(SDA_PIN, SCL_PIN);
  Wire.setClock(400000);

  if (!mpu.begin()) {
    Serial.println("MPU6050 not found!");
    while (1);
  }

  compass.init();

  // Stable configuration
  mpu.setAccelerometerRange(MPU6050_RANGE_8_G);
  mpu.setGyroRange(MPU6050_RANGE_500_DEG);
  mpu.setFilterBandwidth(MPU6050_BAND_21_HZ);

  // Initialize Madgwick
  filter.begin(LOOP_FREQ);
  // filter.beta = 0.04f;   // Stable for slow spacecraft motion

  delay(2000);

  lastMicros = micros();
}

void loop() {

  // ===== Fixed 200 Hz Loop =====
  while ((micros() - lastMicros) < (1000000.0f / LOOP_FREQ));
  lastMicros = micros();

  sensors_event_t a, g, temp;
  mpu.getEvent(&a, &g, &temp);

  // ===== Accelerometer (convert to g, normalize later) =====
  float ax = a.acceleration.x / 9.81f;
  float ay = a.acceleration.y / 9.81f;
  float az = a.acceleration.z / 9.81f;

  // Normalize accelerometer
  float accNorm = sqrt(ax*ax + ay*ay + az*az);
  if (accNorm > 0.0001f) {
    ax /= accNorm;
    ay /= accNorm;
    az /= accNorm;
  }

  // ===== Gyro (rad/s from Adafruit) =====
  float gx = g.gyro.x - gyroBiasX;
  float gy = g.gyro.y - gyroBiasY;
  float gz = g.gyro.z - gyroBiasZ;

  // ===== Magnetometer =====
  compass.read();

  float mx = compass.getX() - magOffsetX;
  float my = compass.getY() - magOffsetY;
  float mz = compass.getZ() - magOffsetZ;

  // Normalize magnetometer
  float magNorm = sqrt(mx*mx + my*my + mz*mz);
  if (magNorm > 0.0001f) {
    mx /= magNorm;
    my /= magNorm;
    mz /= magNorm;
  }

  // ===== Madgwick Update =====
  filter.update(gx, gy, gz, ax, ay, az, mx, my, mz);

  // ===== Get Quaternion =====
  // STEP - 1: MadgwickAHRS.cpp Change it to: #define betaDef 0.04f Or: float beta = 0.04f;
  // STEP 2 — Expose Quaternion (Flight Grade Requirement) Inside MadgwickAHRS.h, under public section, add:
  /* void getQuaternion(float* _q0, float* _q1, float* _q2, float* _q3) {
      *_q0 = q0;
      *_q1 = q1;
      *_q2 = q2;
      *_q3 = q3;}
    Put it below:
  float getYawRadians() */ 
  // These are the changes inside the Documents/Arduino/libraries/Madgwick/src/MadgwickAHRS.h and .cpp

  float q0, q1, q2, q3;
  filter.getQuaternion(&q0, &q1, &q2, &q3);

  Serial.print("Q: ");
  Serial.print(q0,6); Serial.print(" ");
  Serial.print(q1,6); Serial.print(" ");
  Serial.print(q2,6); Serial.print(" ");
  Serial.println(q3,6);

  // Safety normalization
  float qNorm = sqrt(q0*q0 + q1*q1 + q2*q2 + q3*q3);
  q0 /= qNorm;
  q1 /= qNorm;
  q2 /= qNorm;
  q3 /= qNorm;

  // ===== Output Quaternion (Flight-Ready Format) =====
  Serial.print("Q: ");
  Serial.print(q0, 6); Serial.print(" ");
  Serial.print(q1, 6); Serial.print(" ");
  Serial.print(q2, 6); Serial.print(" ");
  Serial.println(q3, 6);

  float roll = filter.getRoll();
  float pitch = filter.getPitch();
  float yaw = filter.getYaw();

  Serial.print("R: ");
  Serial.print(roll);
  Serial.print(" P: ");
  Serial.print(pitch);
  Serial.print(" Y: ");
  Serial.println(yaw);

  Serial.print(millis());
  Serial.print(" ");
}
